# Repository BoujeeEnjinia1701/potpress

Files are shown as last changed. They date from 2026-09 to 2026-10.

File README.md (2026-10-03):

# PotPress

     

**Area:** Water Security · **TRL:** 3 of 9 (proof of concept on paper) · **Value-engineering target:** $1,060 USD · **Difficulty:** 3 of 5

Hydraulic press with printable mold geometry for silver-treated ceramic pot filters, plus a QC flow-rate test jig.

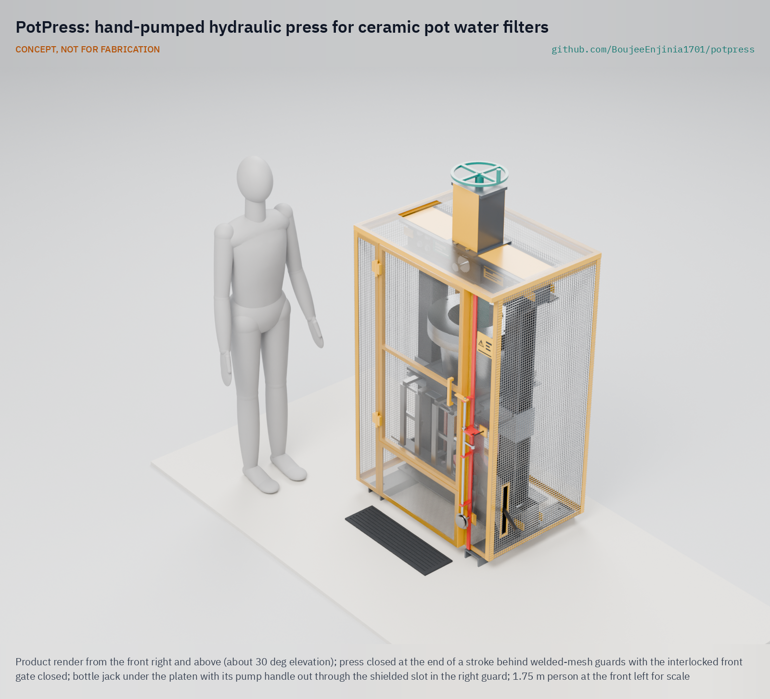
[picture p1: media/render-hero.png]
PotPress: hand-pumped hydraulic press for ceramic pot water filters, product render


[Exploded render](media/render-exploded.png) · [Gate open render](media/render-gate-open.png) · [Lineup render](media/render-lineup.png) · [Interactive 3D model](media/viewer.html) · [Concept blueprint (PDF)](media/concept-blueprint.pdf) · [General arrangement PPR-DWG-001 (PDF)](cad/drawings/PPR-DWG-001.pdf) · [Sizing note PPR-CAL-001](docs/04-calcs/01-sizing.md) · [Prototype build plan](docs/05-build-plan.md) · [Review note](docs/REVIEW.md)

## Concept rationale

The ceramic pot filter already works; what holds small factories back is the press that forms it. A hydraulic press built from standard steel channel, a car-shop bottle jack and molds cast by any aluminum foundry from 3D-printed patterns can be made and repaired in the regions where the filters are needed, instead of imported at several thousand dollars. Every dimension of the pot, the molds, the patterns and the flow gauge comes from one parametric file, so a factory that changes its filter size regenerates all of them together rather than redrawing by hand.

Keeping the design open matters because filter quality depends on details (an even wall, a consistent flow test) that each workshop now solves alone. An open, garage-buildable press lets factories, NGOs and university labs share improvements, compare results on the same geometry and build a second press when the first wears out.

## Burning platform

About 2.1 billion people still lacked safely managed drinking water in 2024, and 106 million drank untreated surface water ([WHO and UNICEF JMP, 2025](https://www.who.int/news/item/26-08-2025-1-in-4-people-globally-still-lack-access-to-safe-drinking-water---who--unicef)). WHO estimates that microbiologically contaminated drinking water causes about 505,000 diarrheal deaths each year, and that at least 1.7 billion people used a drinking water source contaminated with feces in 2022 ([WHO fact sheet, Drinking-water](https://www.who.int/news-room/fact-sheets/detail/drinking-water)).

Locally made ceramic pot filters are an established household option: filters based on the Potters for Peace technology are now made at over 50 independent factories in over 30 countries ([Potters for Peace](https://www.pottersforpeace.org/ceramic-water-filter-project)). Yet a filter press with its aluminum molds cost $3,000 to $3,500 to acquire, and a locally built Nigerian press still cost about $1,000 ([Erhuanga et al., IntechOpen, 2020](https://www.intechopen.com/chapters/71402)). The press is the gate on how many factories can start.

## Where it could be used

### By industry

| Industry | Use |
| --- | --- |
| Household water treatment enterprises | Form filters with an even wall at a small factory and check every one on the QC rack |
| Pottery and ceramics cooperatives | Add filter production to an existing kiln and clay supply with a press they can build and repair |
| Humanitarian and disaster response | Set up filter production near displaced or flood-hit communities without importing a press |
| Public health programs | Supply consistent filters to household water programs and record QC results the same way at every site |
| University and research labs | Study mix, pressing and firing variables on a repeatable press and shared geometry |
| Local fabrication shops and foundries | Build frames and cast molds from open drawings as a local service |

### By country or region

| Country or region | Why it matters there |
| --- | --- |
| Nicaragua | After Hurricane Mitch in October 1998, Potters for Peace set up its first filter production workshop here and distributed over 5,000 filters within six months ([Potters for Peace](https://www.pottersforpeace.org/ceramic-water-filter-project); [University of Pittsburgh](https://www.engineering.pitt.edu/subsites/projects/ceramic-filter/history/)) |
| Guatemala | The filter was designed here in 1981 by Dr. Fernando Mazariegos at the Central American Industrial Research Institute (ICAITI) ([Potters for Peace](https://www.pottersforpeace.org/ceramic-water-filter-project)) |
| Cambodia | One of the countries where Potters for Peace has trained filter producers ([Potters for Peace](https://www.pottersforpeace.org/ceramic-water-filter-project)); a shared press design would let new workshops match established ones |
| Nigeria | A locally built press cost about $1,000 against $3,000 to $3,500 for an imported press and molds, and the team struggled to find a lathe large enough to finish the molds ([Erhuanga et al., IntechOpen, 2020](https://www.intechopen.com/chapters/71402)) |
| United States | The University of Pittsburgh runs research and service-learning projects on filter manufacturing variables, such as sawdust particle size and firing rate, and gives technical support to NGOs that make filters ([University of Pittsburgh](https://www.engineering.pitt.edu/subsites/projects/ceramic-filter/research--activities/)); an open press gives such labs a common reference |

## What sparked the idea

The starting point was the Potters for Peace filter workshop in Nicaragua. Ron Rivera coordinated the organization's work there from 1989, and after Hurricane Mitch tore through Central America in October 1998, Potters for Peace became much more involved in the low-cost filter and set up its first filter production workshop, which distributed over 5,000 filters within six months ([University of Pittsburgh](https://www.engineering.pitt.edu/subsites/projects/ceramic-filter/history/); [Potters for Peace](https://www.pottersforpeace.org/ceramic-water-filter-project)). Its filters are formed with a hand-operated hydraulic truck jack and a two-piece aluminum mold, and filters based on that technology package are now made at over 50 independent factories in over 30 countries ([Potters for Peace](https://www.pottersforpeace.org/ceramic-water-filter-project)). PotPress takes that jack-and-mold principle and asks what it would look like as an openly maintained, parametric design, so that the next workshop can build its press and molds from shared files rather than from a one-off drawing.

## Problem

Ceramic pot filters work well, but local producers have no low-cost way to form them consistently. Imported presses cost about $3,000 to $3,500, locally built ones are one-off designs, and filter quality depends on an even wall and a consistent flow-rate check. Design with, not for: requirements must come from co-design sessions and trials with a working filter factory through a local partner.

## Concept

A 20 t bottle jack on the base lifts a guided platen carrying a cast aluminum female mold against a fixed male mold, forming one filter (280 mm inner rim, 9.9 L working volume) per stroke. The male mold is held by one 60 mm load pin in the top crossbeam for pressing and raised by a hand crank for loading, and the female mold slides out on a carriage for demolding. One parametric filter geometry drives the molds, their 3D-printed casting patterns and a printed T-gauge for the four-station, one-hour flow-rate test rack. TRL 3 calculations: a cycle of about 5.2 min and about 69 pots per 6 h, a frame that stays below yield at 1.5 times the jack rating, 0.66 mm of deflection between the molds at the 10 t working force, every part under 40 kg with the upright joints bolted, and, with the fixed mesh guards and interlocked front gate decided by Amish on 2026-09-26, $1,051 in parts against the $1,060 budget, which Amish raised from $990 on 2026-09-27 to cover the guards. Making the design constructable on 2026-09-30, and adding the fixed shield behind the pump slot on 2026-10-02, raised the parts to about $1,149, and the four guard fixes Amish decided on 2026-10-03 (finer 6.35 mm mesh on the front, gate and roof, small-hole plates at the interlock openings, cover plates on the top beam, covers on the crank bracket) to about $1,169. Value-engineering target: USD 1,060. Estimated cost of the constructable design: USD 1,169 (USD 109 over the target). With those fixes the ISO 13857 desk check of the guard openings, rerun from the model on 2026-10-03, finds every opening meets the standard on paper; nothing above hand pressure is allowed until a competent person signs the check.

Full design precis: [docs/02-concept.md](docs/02-concept.md)

## Key components

- Steel channel frame in welded subassemblies: two UPN 160 beams and back-to-back UPN 100 uprights, bolted at the upright joints with 4 x M16 10.9 each, with spacer tubes and shims
- 20 t bottle jack, guided moving platen and return springs
- Cast aluminum shell molds (female 36.5 kg on its steel base plate, male 23 kg), cast from 3D-printed flat-back patterns and located by two dowels
- Mold carriage on slide rails with a hinged front extension that folds down, and male mold slide with hand crank, one load pin and a pin-presence interlock
- Four-station (2 x 2) QC flow-test rack with printed T-gauges and collection buckets

The working bill of materials is in [bom/bom.csv](bom/bom.csv).

## Building the prototype

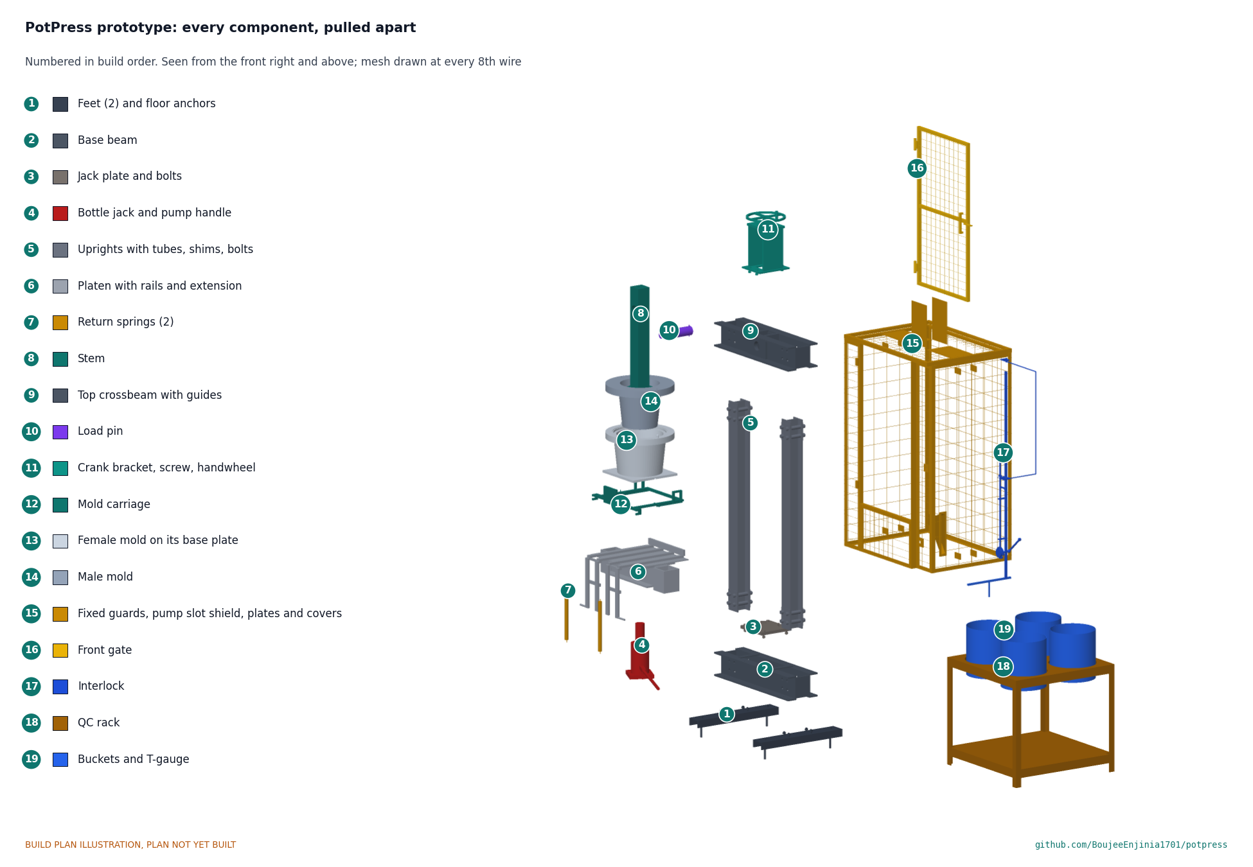
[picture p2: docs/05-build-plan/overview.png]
Every component of the PotPress prototype, pulled apart and numbered in build order


The [prototype build plan](docs/05-build-plan.md) (PPR-BLD-001, plan, not yet built) shows how to make each component and fit it to the next, in 14 making sketches, 11 joint close-ups and 18 assembly steps drawn from the model. The frame, platen, carriage and guards are sawn, drilled and stick welded from steel channel, plate and galvanized mesh; the two molds are sand cast by a local foundry from 3D-printed flat-back patterns and lead-free scrap, then lapped and hand finished, with no lathe needed. Writing the plan made the design constructable: seventeen changes, such as an open-topped male mold, dowel location for the molds, M16 joint bolts with spacer tubes and a floating lead screw nut, are recorded in [PPR-DDR-004](docs/decisions/0004-design-for-construction.md). The parts now cost about $1,169, $109 over the $1,060 value-engineering target, a hypothetical control target; the design decisions register lists the savings worth trying.

## Safety

> **Safety:** Hydraulic presses store significant energy. Guard pinch points, press only with the gate closed and the load pin fully home (the interlock enforces this), and never exceed the jack rating. Molds are heavy; clay dust contains silica; silver compounds are corrosive. Passing the flow test does not prove a filter removes pathogens. See the safety section of the [design precis](docs/02-concept.md).

## Repository layout

| Folder | Contents |
| --- | --- |
| `docs/` | Problem, concept, requirements, calculations and design decisions |
| `cad/src/` | build123d Python source, the source of truth for all geometry |
| `cad/step/`, `cad/stl/` | Exported models for FreeCAD, other CAD tools and printing |
| `cad/drawings/` | 2D sketches and dimensioned drawings |
| `bom/` | Bill of materials |
| `electronics/` | KiCad schematics and PCB layouts |
| `firmware/` | Microcontroller code |
| `media/` | Renders, perspectives and photos |
| `build-log/` | Dated prototyping notes |

## Documentation

Controlled documents follow the portfolio [documentation standard](.kit/STANDARDS.md). Each carries a document ID (PPR-PRC-001 for the precis), a version and a revision history. Branded PDFs are built with `python .kit/render.py` and attached to GitHub Releases when a document is tagged, for example `PPR-PRC-001/v1.0`.

## Credits

Designed by Amish Chadha. See [CONTRIBUTORS.md](CONTRIBUTORS.md) for roles. To cite this design, use [CITATION.cff](CITATION.cff) (GitHub shows it as "Cite this repository").

AI assistance (Claude) was used to accelerate concept renders, prototype documentation and first-pass sizing calculations. Design direction and all decisions are Amish Chadha's, recorded in this repository's decision records (`docs/decisions/`).

## Licenses

- **Hardware** (CAD, drawings, BOM, electronics): [CERN-OHL-S v2](LICENSE)
- **Software** (firmware, scripts, notebooks): [MIT](LICENSE-SOFTWARE)

A project of the [Design Molecule](https://designmolecule.com) lab.

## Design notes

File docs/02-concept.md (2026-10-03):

---
doc_id: PPR-PRC-001
title: PotPress design precis
project: PotPress
doc_type: Design precis
version: "0.11"
status: Draft
date: '2026-10-03'
author: Amish Chadha
license: CERN-OHL-S-2.0
revisions:
- version: "0.1"
  date: '2026-09-24'
  author: Amish Chadha
  change: Initial scaffold
- version: "0.2"
  date: '2026-09-25'
  author: Amish Chadha
  change: Populate to TRL 2 (architecture, first-order numbers, material flow, safety, media)
- version: "0.3"
  date: '2026-09-25'
  author: Amish Chadha
  change: TRL 3 update; design choices decided by Amish (PPR-DDR-001); numbers corrected to PPR-CAL-001 (shell molds, 2 x UPN 160 base, one 60 mm pin, 2 x 2 QC rack, cost)
- version: "0.4"
  date: '2026-09-25'
  author: Amish Chadha
  change: Recommendations accepted by Amish (DDR-002); bolted upright joints, hinged rail extension, pin-presence interlock, lead-free scrap, budget $930; numbers from PPR-CAL-001 v0.2
- version: "0.5"
  date: '2026-09-26'
  author: Amish Chadha
  change: Budget top-up approved by Amish; budget $990, R10 met on paper
- version: "0.6"
  date: '2026-09-26'
  author: Amish Chadha
  change: Guarded version (decided by Amish 2026-09-26)
- version: "0.7"
  date: '2026-09-27'
  author: Amish Chadha
  change: Cost overrun decided by Amish on 2026-09-27; budget $1,060, R10 met on paper
- version: "0.8"
  date: '2026-10-01'
  author: Amish Chadha
  change: Budget treated as a value-engineering target
- version: "0.9"
  date: '2026-10-02'
  author: Amish Chadha
  change: 'Decisions of 2026-10-02 carried in: ISO 13857 desk check now as a hold point, pump slot inner shield, handle operating space, working force found in trials from about 2 t, demolding confirmed with potters'
- version: "0.10"
  date: '2026-10-02'
  author: Amish Chadha
  change: 'Approved follow-ups carried out: pump slot shield designed; ISO 13857 desk check done (PPR-CAL-001 v0.9) with its findings; cost $1,149'
- version: "0.11"
  date: '2026-10-03'
  author: Amish Chadha
  change: 'Four guard fixes decided by Amish (2026-10-03): 6.35 mm mesh on the front and roof, small-hole plates, top beam cover plates, crank bracket covers; desk check rerun, every opening meets on paper; R9 met on paper; cost $1,169'
---

# PotPress design precis

PotPress is a hand-pumped hydraulic press that forms one ceramic pot filter per stroke between a cast aluminum female mold and male mold, plus a four-station rack for the standard one-hour flow-rate test. A 20 t bottle jack on the base lifts a guided platen carrying the female mold against a fixed male mold, whose stem is held by one load pin in the top crossbeam for pressing and raised by a hand crank for loading. One parametric filter geometry drives the molds, the 3D-printed casting patterns and the printed flow gauge. The TRL 3 calculations (PPR-CAL-001) give a cycle of about 5.2 min and about 69 pots per 6 h, a strong frame at 1.5 times the jack rating, every part under 40 kg with the frame bolted at the upright joints, and, in the guarded version, a parts cost of $1,051 against the $1,060 value-engineering target (the target stood at $990 before the guards were added, PPR-DDR-003). The press works inside fixed welded-mesh guards with a hinged front gate that is interlocked with the jack release, as decided by Amish on 2026-09-26 (PPR-DDR-003). The other design choices below were decided by Amish on 2026-09-25 (PPR-DDR-001 and PPR-DDR-002).

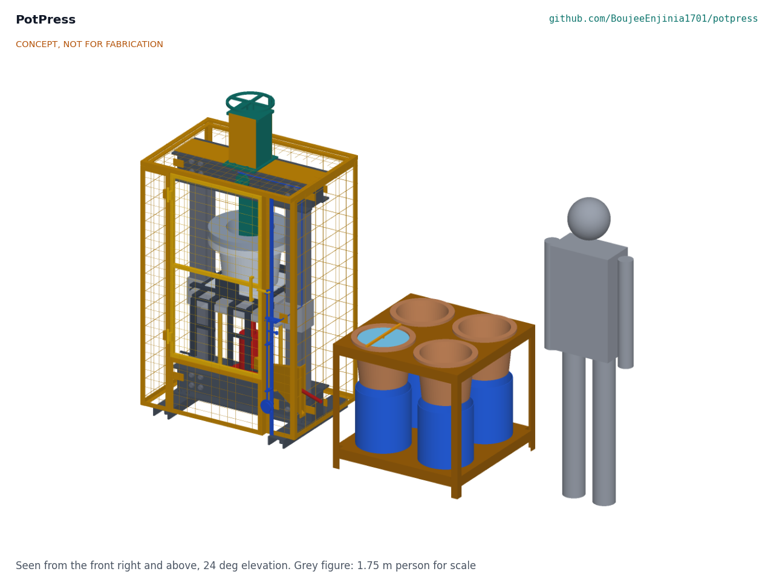
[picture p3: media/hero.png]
Hero render


*Figure 1. PotPress with the 2 x 2 QC flow-test rack and a 1.75 m person for scale. The press is shown closed at the end of a pressing stroke, inside its mesh guards with the front gate closed; the mesh is drawn at every eighth wire.*

## How it works

1. **Load.** With the platen down and the jack release open, the female mold rim is at about 921 mm. The operator opens the front gate, swings the hinged rail extension up onto its stop lugs, slides the carriage out 430 mm on the rails, lays a polyethylene release liner in the female mold, places a weighed charge of about 7.5 kg of clay, burnout and water mix, and slides the carriage back to its end stop.
2. **Lower the male mold.** A handwheel on top of the frame turns a self-locking Tr24 x 5 lead screw that runs the male mold stem down 200 mm (40 turns) through the top crossbeam until the pin bores line up. The operator inserts the 60 mm load pin through the beam and stem. From then on the pin, not the screw, carries the press force.
3. **Press.** The operator closes the front gate, which lets the guard-locking interlock free the jack release T-handle; closing the release locks the gate shut. The operator then pumps the jack through the slot in the right side guard, about 70 strokes. The platen, guided by sleeves on both uprights, lifts the female mold about 110 mm and squeezes the charge into the gap between the molds. The male flange centers in a tapered lip on the female mold and lands on a stop face, so the 15 mm wall and rim are set by the molds, not by how hard the operator pumps. Excess mix squeezes into a flash groove at the rim for trimming.
4. **Open and demold.** The operator opens the jack release with the T-handle outside the guard; the platen's weight and two springs return it, and only then does the interlock let the gate open. The operator pulls the pin and cranks the male mold up, leaving its tip 70 mm above the female rim. The carriage slides out toward the operator and tilts on its pivots so the pot, still in its liner, turns out onto a drying board. Between loads the rail extension folds down, so the press stands 840 x 655 mm.
5. **Dry, fire, treat.** Drying, firing and silver treatment follow the factory's existing practice and are outside PotPress.
6. **Test.** Fired pots are soaked, hung by their rims in the QC rack over collection buckets, filled to 10 mm below the rim and read after one hour with the printed T-gauge. The reading is corrected to 25 °C with the water temperature.

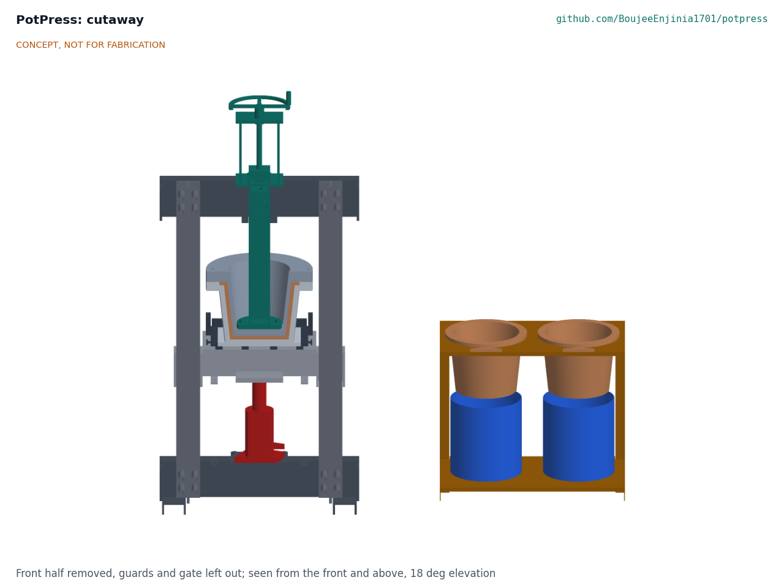
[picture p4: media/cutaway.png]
Cutaway


*Figure 2. Cutaway through the closed press and the QC rack, showing the pressed pot between the molds, the shell molds and the load path.*

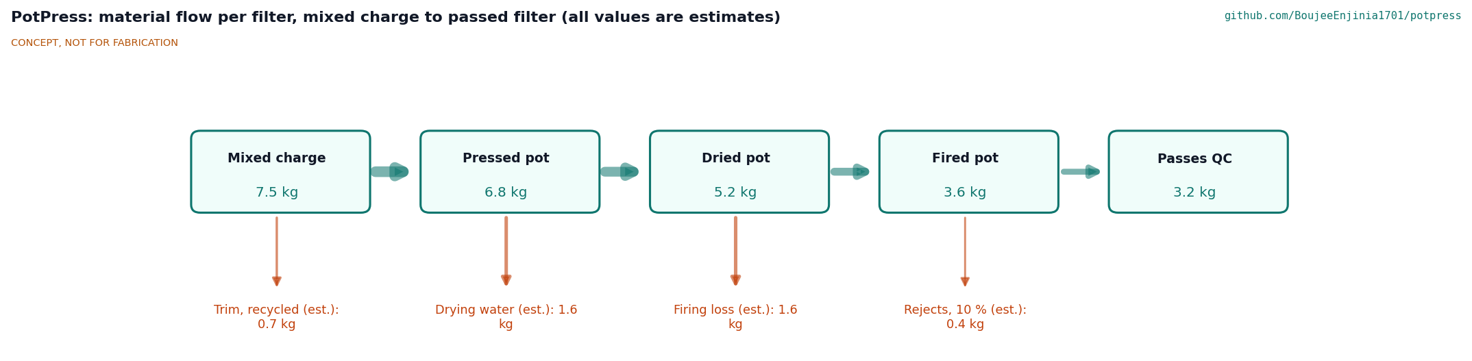
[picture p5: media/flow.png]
Material flow


*Figure 3. Material flow for one filter, from mixed charge to a filter that passes QC, in kg. All values are estimates from PPR-CAL-001.*

## Main components

Numbers match the exploded view (Figure 4), `bom/bom.csv` and the general arrangement drawing PPR-DWG-001.

*Table 1. Main components.*

| # | Component | Choice | Notes |
| --- | --- | --- | --- |
| 1 | Base beam and feet | Two UPN 160 channels 840 mm with a 100 mm gap, 20 mm jack plate, two UPN 100 feet bolted on | Same section as the top beam; the TRL 2 single UPN 100 would reach about 1,071 MPa |
| 2 | Uprights | Two UPN 100 channels back to back each side, about 1.40 m, sandwiched in the beam gaps at 600 mm centers and bolted to both beams with 4 x M20 8.8 per joint | 54 MPa in tension, bolts 75 MPa in double shear at 294 kN; 29.4 kg per pair |
| 3 | Top crossbeam | Two UPN 160 channels, 12 mm web doublers and a 62 mm pin bore at the center, UHMW-PE stem guides | 190 MPa at 294 kN |
| 4 | 20 t bottle jack | Standard jack, 150 mm stroke, about 60 mm ram | Uses 110 mm of stroke |
| 5 | Moving platen | Two UPN 140 channels, 6 mm deck, jack pad, 150 mm guide sleeves on the uprights | 38.9 kg, the heaviest part as fabricated |
| 6 | Return springs | Two tension springs | Gravity returns the platen; the springs keep it seated |
| 7 | Rails, hinged extension and carriage | Four flat-bar rails at 60 and 170 mm each side, fixed to 320 mm in front of the axis, with a 330 mm extension on barrel hinges and stop lugs that folds down; carriage frame with handle and tilt pivots | Moves the female mold out of the pinch zone; 43 N·m on the hinge with the carriage out |
| 8 | Female mold | Cast aluminum shell, 20 mm behind the cavity, 30 mm solid base, 410 mm flange with a locating lip, rim counterbore and flash groove; 24.3 kg | A solid block would weigh about 57 kg |
| 9 | Male mold | Cast aluminum hollow plug, 15 mm shell and 30 mm tip, 390 mm rim-forming flange; 17.9 kg | A solid plug would weigh about 41 kg |
| 10 | Male mold slide | SHS 90 x 8 stem with a pin block, one 60 mm 42CrMo4 load pin, crank bracket, Tr24 x 5 lead screw and 260 mm handwheel | The screw only lifts; the pin carries the load |
| 11 | Pressed filter pot | The product, shown for context | Not costed |
| 12 | QC flow-test rack | 2 x 2 stations, 780 x 780 x 550 mm, steel angle and plywood | Within R11's 0.8 x 0.8 m |
| 13 | Printed T-gauge | PETG dipstick; 1.0 L is 16.7 mm on the scale | Scale generated from the geometry |
| 14 | Collection buckets | 20 L food-grade HDPE | |
| 16 | Fixed mesh guards, pump slot shield and guard fixes | Welded mesh on 25 x 25 x 3 angle frames: 12.7 x 12.7 x 1.6 mm (about 11 mm clear) on both sides and the back; 6.35 x 6.35 x 0.9 mm (about 5.5 mm clear) on two front strips, a lower front panel and a roof around the top beam; standoffs to the beams; a framed 30 x 272 mm pump handle slot in the right side with a fixed inner shield behind it, a tunnel of 2 mm sheet round the handle's path to the jack body; small-hole plates at the release shaft and pin cable; 3 mm cover plates on the top beam; 2 mm covers on the crank bracket | Mesh planes 940 x 675 mm; about 4.3 m² of mesh, 1.1 m² of it 6.35 mm; shield 2.8 kg; plates and covers 4.4 kg |
| 20 | Front gate | 532 x 1,063 mm, 20 x 20 x 2 tube frame with 6.35 mm mesh (2026-10-03), two lift-off hinges on the left front post, pull handle and striker tongue; opens outward to the left | Clears the carriage, molds and rail extension (540 mm opening) |
| 21 | Gate interlock and release extension | Mechanical guard-locking bolt on the right front post, link rod and lock bar to a blocking cam on the jack release extension; T-handle outside the lower front panel; the pin-presence plunger acts on the same lock bar | No electrics |

Casting patterns, release liners, fasteners and consumables, and the QC timer and thermometer are BOM items 15 and 17 to 19 and are not modeled. The guards are modeled with their mesh drawn at every eighth wire (101.6 mm) so the views stay readable; the appearance model draws every wire.

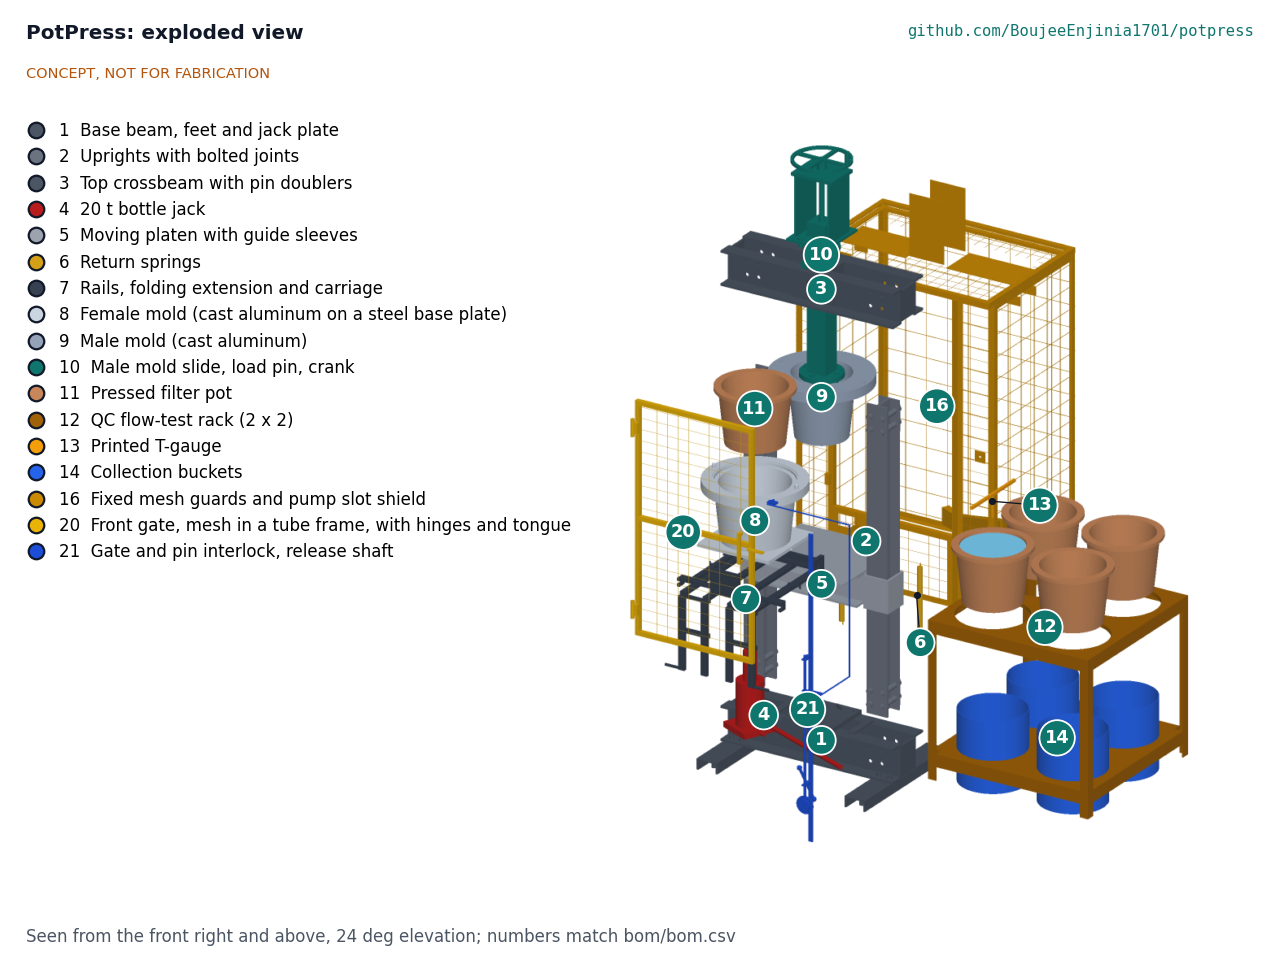
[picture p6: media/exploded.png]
Exploded view


*Figure 4. Exploded view with numbered callouts matching the BOM.*

## Key numbers

All values are estimates from PPR-CAL-001, which lists its assumptions and the results against every requirement.

*Table 2. Key numbers at TRL 3.*

| Quantity | Value | Basis |
| --- | --- | --- |
| Filter volume | 12.30 L to the brim; 9.91 L working | Inner rim 280 mm, floor 230 mm, depth 240 mm |
| Pot masses | Charge 7.47 kg; pressed 6.79 kg; fired 3.61 kg | RDI-C recipe, 1.64 kg/L pressed |
| Mean pressure | 0.52 to 1.05 MPa at 5 to 10 t; 2.10 MPa at 20 t | 0.0935 m² projected |
| Frame at 294 kN | Beams 190 MPa, uprights 54 MPa, pin 258 MPa (yield 650), joint bolts 75 MPa | S275; 42CrMo4 pin; M20 8.8 bolts |
| Deflection between molds | 0.61 mm at 10 t; 1.84 mm at 294 kN | R3 (1 mm at 10 t) met on paper |
| Travel | 110 mm pressing of 150 mm stroke; 310 mm opening against 270 mm needed | R5 met |
| Cycle | 5.2 min; 69 pots per 6 h | R4 met |
| Wall evenness | ±1.40 mm as cast; ±0.43 mm finished to templates | R2 at risk |
| Flow gauge | 0.1 L is 1.69 mm; 2.3 % per °C near 25 °C | R6 met |
| Size and mass | Press 840 x 655 x 1,806 mm unguarded; 940 x 700 mm guarded, with the rail extension folded; 298 kg plus 7 kg of joint bolts and about 45 kg of guards (estimate); heaviest part 38.9 kg; rack 780 x 780 mm | R8 met on paper; R11 met on paper at the 0.7 m limit |
| Guarding | Mesh 12.7 mm pitch at the sides and back, 100 to 110 mm from moving parts; 6.35 mm pitch on the front, gate and roof, 39 to 77 mm from moving parts; pump slot enclosed by a fixed inner shield; interlock openings closed to 4 and 2 mm gaps; top beam and crank bracket covered | ISO 13857 desk check rerun from the model on 2026-10-03 with the four guard fixes decided by Amish (PPR-CAL-001, section 15): all 23 openings meet on paper; not yet signed; R9 met on paper |
| Cost | Press $1,086, QC rack $83, total $1,169 (constructable design with the pump slot shield and the guard fixes) | Value-engineering target: USD 1,060. Estimated cost of the constructable design: USD 1,169 (USD 109 over the target) |

The working force is still an assumption. Henry, Maley and Mehta (2013) formed round-bottom filters with a 2 t car jack ([IJSLE 8 (1)](https://ojs.library.queensu.ca/index.php/ijsle/article/view/4532)), which suggests the real force may be well below 5 to 10 t; the frame is sized for the full 20 t jack either way. Decided by Amish on 2026-10-02: every structural check stays at the full 20 t jack, and the working force is a process setting found in pressing trials with a partner factory, starting near 2 t and stepping up.

## Key design choices

These were decided by Amish on 2026-09-25: go with recommendation (PPR-DDR-001 items 1 to 8 and 10 to 15; PPR-DDR-002), except the guarded version, decided by Amish on 2026-09-26 (PPR-DDR-003).

- **Jack below, pushing the female mold up.** A bottle jack must stand upright, so it sits on the base and lifts the platen, and the male mold hangs from the top beam.
- **Male mold lift by hand crank with one load pin and an interlock.** A standard jack gives only 150 mm of stroke, so the crank provides the other 200 mm of opening. The TRL 2 pair of 30 mm pins fails in bending by calculation; one 60 mm alloy-steel pin carries the force, and a mechanical pin-presence interlock stops the jack release valve closing unless the pin is fully home.
- **Molds cast in aluminum from printed patterns, from lead-free scrap.** Cast as shells to keep them under 25 kg, with the cavity finished by hand to printed templates. Scrap must be lead-free (for example cast wheels or pistons; no free-machining bar). The fiber-reinforced concrete backed variant stays documented as a low-cost alternative; building it is TRL 4 work and on hold.
- **Welded subassemblies, bolted at the upright joints.** The base beam, top beam, uprights and platen are welded separately and joined with 4 x M20 8.8 bolts at each of the four upright joints, so no part exceeds 40 kg. Fully welded, the frame would be one 147 kg piece.
- **Molds close on a metal stop.** The male flange lands on the female stop face, so frame stretch does not set the wall; R3 judges deflection at the 10 t working force.
- **Demold by sliding out and tilting the carriage,** on a rail extension that folds down between loads.
- **Manual QC rack with printed T-gauge.** The rack is 2 x 2 stations in 0.8 x 0.8 m; a load-cell logger stays a later option.
- **Default acceptance band 1.0 to 2.5 L/h in the first hour, corrected to 25 °C.** Each factory may set its own band.
- **Value-engineering target $1,060.** This is a hypothetical control target, not a limit. The priced BOM was $984 after the bolted joints and rail hinges, against a $990 target. The guarded version adds $67 and brings the BOM to $1,051, $61 over that earlier target; the target was set at $1,060 on 2026-09-27, since guarding is a safety requirement (PPR-DDR-003). The estimate was then within the target, $9 (0.8 %) under; the constructable design (PPR-DDR-004) and the pump slot shield (2026-10-02) bring it to $1,149, and the four guard fixes Amish decided on 2026-10-03, accepting their cost, to $1,169, $109 over the target.
- **Guarded version (decided by Amish, 2026-09-26; PPR-DDR-003).** Fixed welded-mesh guards on the sides, back and roof, and a hinged front gate with a mechanical guard-locking interlock on the jack release. A hand pump has no power to switch off, so the interlock acts on the one thing that lets the jack build pressure: the release valve. With the gate open the release cannot be closed, so pumping moves nothing; with the release closed the gate cannot be opened. This was chosen over two-hand control, which does not suit a one-handed pump lever, and over hold-to-run alone, which a hand pump already is but which leaves the other hand free to reach the molds.

## Safety

> **Safety:** PotPress is a 20 t hydraulic press with heavy moving parts, and the workshop around it handles silica-bearing clay dust and silver compounds. Treat each of these as a hazard at every stage.

- **Crushing and pinch points.** The gap between the molds, the platen and the uprights, and the carriage rails can crush fingers and hands. The guarded version (PPR-DDR-003) encloses them: fixed welded-mesh guards on the sides, back and roof, fixed front strips and a lower front panel, and a hinged front gate. The gate's guard-locking interlock holds the jack release open unless the gate is shut, and holds the gate shut while the release is closed. The pump handle works through a framed slot in the right side guard, well below the platen, with a fixed steel tunnel behind the slot so that only the handle can be reached through it, and the release T-handle sits outside the lower front panel. The carriage has an end stop so it cannot be pushed past the male mold. Keep fingers clear of the rail extension hinges when folding it, and deploy it only onto its stop lugs; the extension cannot be deployed with the gate shut.
- **Guard openings (ISO 13857 desk check, 2026-10-02, rerun 2026-10-03).** Decided by Amish on 2026-10-02: the check is done now as a desk check from the tables and the model's distances, signed by a competent person, and is a hold point before any force above hand pressure. The first run found the 12.7 mm mesh on the front and roof too coarse for its 39 to 77 mm distance from moving parts, the release shaft and pin cable openings too large, and the top beam and crank bracket open from above. Amish decided on 2026-10-03: "PotPress - move forward with the four guard fixes. I accept the cost." The front strips, lower front panel, front gate and roof now carry 6.35 mm (1/4 in) mesh with 0.9 mm wire, about 5.5 mm clear, which Table 4 allows 5 mm from a moving part; plates close the two interlock openings to a 4 mm gap round the release shaft and 2 mm round the pin cable; 3 mm plates cover the top beam from the crank bracket to the beam ends, including the open tops of the upright channels; 2 mm sheet closes the front and back of the crank bracket. The sides and back keep the 12.7 mm mesh, 100 to 110 mm from moving parts, and the 30 x 272 mm pump slot stays enclosed by its fixed inner shield. The rerun check finds every one of the 23 openings meets on paper (PPR-CAL-001, section 15). The check is not yet signed; nothing above hand pressure until it is. The 158 mm the pump handle stands outside the guard while in use is operating space, marked on the floor layout. Never remove a guard or defeat the interlock, and inspect both before each shift.
- **Load pin and stored energy.** One 60 mm pin carries the whole press force. Never press unless the pin is fully home through both beam webs and the stem; the guard includes a pin-presence interlock that stops the jack release closing until the pin is home. Check the bolted upright joints for tightness before each shift. Never exceed the jack rating, never add a cheater bar to the pump handle, and never adjust the jack's relief valve. Release pressure fully before opening the gate or pulling the pin.
- **Falling and tipping.** The molds weigh about 24 and 18 kg and the press about 305 kg with its bolts, with its center of mass about 0.8 m up. A push of about 750 N at 1 m tips it forward, so anchor the base to the floor, lift molds with two people and wear safety boots. The lead screw is self-locking, so the male mold holds its height if the handwheel is released; still keep hands out from under it.
- **Silica dust.** Dry clay and rice husk ash contain crystalline silica, which causes silicosis. Keep mixing and trimming wet, sweep damp, and wear a fitted P2 or N95 respirator for dry work.
- **Molten aluminum and alloy.** Casting is done by a foundry, not at the press. Scrap containing lead (free-machining alloys) must not be used for mold faces that touch a drinking-water product.
- **Silver compounds.** Silver nitrate is corrosive to skin and eyes and toxic to aquatic life; handle colloidal silver with gloves and eye protection and never pour it into waterways. Silver treatment is outside PotPress but happens in the same workshop.
- **Heat.** Kilns reach about 900 °C. Kilns are outside PotPress but share the site.
- **Water safety claims.** PotPress makes consistent pots; it does not certify them. A filter that passes the flow test is not proven to remove pathogens. Factories must verify bacteria removal by laboratory testing and follow the CMWG recommendations.

## Open questions

- What pressing force gives a well-consolidated wall with a typical mix? Found in pressing trials with a partner factory, starting near 2 t and stepping up (decided, 2026-10-02).
- Can hand finishing to printed templates reach ±0.3 mm on a 400 mm casting (R2, R7)?
- Handwheel height of about 1.8 m: a side crank through a bevel gear would be easier to reach.
- Confirm the demolding method with the potters at the first partner factory; the tipping pins stay for the prototype, and if the potters object the pot is lifted out in its liner (decided, 2026-10-02). Check whether a liner leaves marks that affect flow.
- Choose the first partner factory or organization (left open under the portfolio rule).

Concept media: [blueprint sheet](../media/concept-blueprint.pdf), [interactive 3D model](../media/viewer.html). General arrangement: [PPR-DWG-001](../cad/drawings/PPR-DWG-001.pdf).

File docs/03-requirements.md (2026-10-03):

---
doc_id: PPR-REQ-001
title: PotPress requirements
project: PotPress
doc_type: Requirements
version: "0.12"
status: Draft
date: '2026-10-03'
author: Amish Chadha
license: CERN-OHL-S-2.0
revisions:
- version: "0.1"
  date: '2026-09-24'
  author: Amish Chadha
  change: Initial scaffold
- version: "0.2"
  date: '2026-09-25'
  author: Amish Chadha
  change: First measurable requirements for TRL 2, with concept status
- version: "0.3"
  date: '2026-09-25'
  author: Amish Chadha
  change: Apply Amish's 2026-09-25 decisions (PPR-DDR-001); R10 target $720, R6 band decided; status from PPR-CAL-001; proposed changes to R3 and R11
- version: "0.4"
  date: '2026-09-25'
  author: Amish Chadha
  change: Recommendations accepted by Amish (DDR-002); R3 at 10 t with a metal stop, R9 pin interlock, R10 $930, R11 rack 0.8 x 0.8 m and folded rails, R12 lead-free scrap; status from PPR-CAL-001 v0.2
- version: "0.5"
  date: '2026-09-26'
  author: Amish Chadha
  change: Budget top-up approved by Amish; R10 target $990, status met on paper
- version: "0.6"
  date: '2026-09-26'
  author: Amish Chadha
  change: Guarded version (decided by Amish 2026-09-26)
- version: "0.7"
  date: '2026-09-27'
  author: Amish Chadha
  change: Cost overrun decided by Amish on 2026-09-27; R10 target $1,060, status met on paper
- version: "0.8"
  date: '2026-09-30'
  author: Amish Chadha
  change: Status from PPR-CAL-001 v0.6 after the design for construction (PPR-DDR-004); R10 not met on paper; no requirement text changed
- version: "0.9"
  date: '2026-10-01'
  author: Amish Chadha
  change: Budget treated as a value-engineering target; R10 reported against the target
- version: "0.10"
  date: '2026-10-02'
  author: Amish Chadha
  change: 'Decisions of 2026-10-02: R9 at risk until the pump slot shield is designed and the ISO 13857 desk check is signed; R9 verification and the force assumption restated'
- version: "0.11"
  date: '2026-10-02'
  author: Amish Chadha
  change: 'Approved follow-ups carried out: pump slot shield designed and modelled; ISO 13857 desk check done from the model (PPR-CAL-001 v0.9), R9 at risk to not met on paper until the guard changes it found are made and the check is signed; R10 $1,149, $89 over the target'
- version: "0.12"
  date: '2026-10-03'
  author: Amish Chadha
  change: 'Four guard fixes decided by Amish (2026-10-03) modelled; desk check rerun (PPR-CAL-001 v0.10), all 23 openings meet on paper; R9 not met to met on paper (check not yet signed); R10 $1,169, $109 over the target'
---

# PotPress requirements

These requirements were checked by calculation at TRL 3 (PPR-CAL-001 v0.10). They are not yet validated with a filter factory and will be revised after co-design sessions (see PPR-PRB-001). With the design made constructable (PPR-DDR-004, 2026-09-30), one is over the value-engineering target (R10, the parts cost of $1,169 against the $1,060 target, $109 over), two are at risk (R2 and R7) and nine are met on paper, R9 among them since the four guard fixes Amish decided on 2026-10-03 close every opening the ISO 13857 desk check found short (the check is not yet signed by a competent person); see Table 2. Amish's decisions of 2026-09-25 are recorded in PPR-DDR-001 and PPR-DDR-002: the R6 default band, R3 judged at the 10 t working force, the R10 target of $930 (topped up to $990 by Amish on 2026-09-26 and raised to $1,060 by Amish on 2026-09-27, PPR-DDR-003), the R11 rack area of 0.8 x 0.8 m, the pin-presence interlock in R9 and lead-free scrap in R12. The guarded version and the guarding detail in R9 were decided by Amish on 2026-09-26 (PPR-DDR-003).

The **reference filter** used throughout is the common flowerpot form: inner rim diameter 280 mm, inner depth 240 mm, wall 15 mm, flat rim about 345 mm across, about 12 L to the brim and about 10 L working volume (dimensions are estimates based on the 280 by 250 mm form reported by [Potters for Peace](https://www.pottersforpeace.org/ceramic-water-filter-project)).

*Table 1. Requirements.*

| ID | Requirement | Target | Verification (TRL 3 or later) |
| --- | --- | --- | --- |
| R1 | Form the reference filter | Inner rim 280 mm, inner depth 240 mm, wall 15 mm, flat rim; geometry set by parameters in one source file | Model check; later measurement of pressed pots |
| R2 | Even wall | Wall thickness within ±1 mm around the circumference and from pot to pot; molds self-center to within 0.5 mm | Tolerance stack and guide design; later sectioned pots |
| R3 | Pressing force and frame strength | 20 t (196 kN) rated jack; frame, pin, bolts and platen carry 1.5 times the jack rating (294 kN) without yield; deflection between the molds under 1 mm at the 10 t maximum working force, with the molds closing on a metal stop so frame stretch does not set the wall (decided by Amish, 2026-09-25) | Beam and pin calculation; later proof load |
| R4 | Throughput | Press cycle of 6 min or less with two operators, so 50 or more pots per 6 h of pressing | Cycle breakdown; later timed trial |
| R5 | Mold opening | Male mold lifts at least 30 mm clear of the female rim so the mold carriage slides out for loading and demolding; pressing stroke within one jack stroke | Kinematic layout |
| R6 | Flow-rate QC | Rack tests 4 soaked filters at once; T-gauge reads flow over 1 h to 0.1 L/h; repeatability ±0.1 L/h; acceptance band set per factory (default 1.0 to 2.5 L/h in the first hour, corrected to 25 °C; decided by Amish, 2026-09-25) | Gauge calibration by volume; later repeat tests |
| R7 | Molds made locally | Molds cast from 3D-printed patterns printed on a 250 x 250 mm class printer; finishing with hand tools and a drill press; no lathe over 300 mm swing | Pattern split and finishing review with a foundry |
| R8 | Frame built locally | Standard steel channel and plate; stick welding, drilling and bolting only; heaviest single part 40 kg or less for two-person handling | Part list and mass estimate |
| R9 | Safe operation | Fixed welded-mesh guards on the sides, back and roof and a hinged front gate enclose every pinch point of the molds, platen, jack and carriage; guard openings and their distance from moving parts prevent finger reach into the pinch zone, judged against ISO 13857; a guard-locking gate interlock stops the jack release closing (so the jack cannot be pumped to build pressure) unless the gate is shut, and keeps the gate shut while the release is closed; jack pump and release worked from outside the guard; a pin-presence interlock prevents pressing unless the load pin is fully home (pin interlock decided by Amish, 2026-09-25; guarding decided by Amish, 2026-09-26) | Hazard review and guard layout in the model; ISO 13857 desk check signed by a competent person before any force above hand pressure (decided by Amish, 2026-10-02) |
| R10 | Affordable | Press plus QC rack at or under the $1,060 value-engineering target in parts (a hypothetical control target; raised from $600 to $720 and then to $930 by Amish, 2026-09-25; topped up to $990 by Amish, 2026-09-26; raised to $1,060 by Amish, 2026-09-27) | Priced BOM (`bom/bom.csv`) |
| R11 | Footprint | Press within 1.0 x 0.7 m floor area and 2.0 m height, with the rail extension folded; QC rack within 0.8 x 0.8 m (relaxed from 0.8 x 0.5 m by Amish, 2026-09-25) | Model check |
| R12 | Product-safe materials | Faces that touch clay or test water are aluminum, food-grade polyethylene or stainless steel; no lead-based paint or oiled release agents on mold faces; molds cast from lead-free scrap (no free-machining alloys; decided by Amish, 2026-09-25) | Material list review |

*Table 2. Status against each requirement at TRL 3 (from PPR-CAL-001 v0.10 and, for R9, R10 and R11, the guarded model and BOM; least certain first).*

| ID | TRL 3 value | Status |
| --- | --- | --- |
| R9 | Guards, gate and interlocks modeled (PPR-DDR-003); fixed inner shield behind the 30 x 272 mm pump slot (2026-10-02), so the slot opens only onto the pump handle; the four guard fixes decided by Amish on 2026-10-03 modelled: 6.35 mm mesh on the front strips, lower front panel, gate and roof, small-hole plates at the release shaft and pin cable, cover plates on the top beam, covers on the crank bracket. ISO 13857 desk check rerun from the model (PPR-CAL-001, section 15): all 23 openings meet Table 4 | Met on paper. The desk check is not yet signed by a competent person, a hold point before any force above hand pressure |
| R10 | Priced BOM $1,169 (press $1,086, QC rack $83) with the constructable design (PPR-DDR-004), the pump slot shield and the guard fixes against $1,060 | **Over the value-engineering target by $109** (10.3 %) |
| R2 | Wall ±1.40 mm as cast; ±0.44 mm with molds hand-finished to templates; coaxial ±0.44 mm via match-drilled dowels | **At risk** |
| R7 | 16 flat-back pattern segments for a 250 mm printer, no core boxes; no lathe needed; cavity hand finishing unproven | **At risk** |
| R1 | Reference filter from `PARAMS` in `cad/src/model.py`: 12.30 L to the brim, 9.91 L working | Met on paper |
| R3 | No yield at 294 kN: beams 190 MPa, uprights 54 MPa, 60 mm pin 272 MPa (yield 650), M16 joint bolts 117 MPa, male flange on the stop 62 MPa. Deflection between the molds 0.66 mm at 10 t (1.97 mm at 294 kN) | Met on paper |
| R4 | 5.2 min cycle, 69 pots per 6 h | Met on paper, thin margin |
| R5 | 310 mm opening against 270 mm needed; 110 of 150 mm jack stroke | Met on paper |
| R6 | 4 stations; 0.1 L is 1.69 mm on the gauge; temperature correction to 25 °C | Met on paper; repeatability not verifiable at TRL 3 |
| R8 | Heaviest part 39.6 kg (platen); upright joints bolted, largest frame part 38.0 kg | Met on paper |
| R11 | Press 940 x 700 mm guarded with the rail extension folded (the pump handle stands 158 mm outside the right guard while in use), 1,806 mm tall; QC rack 780 x 780 mm | Met on paper, at the 0.7 m depth limit with no margin |
| R12 | Aluminum faces, polyethylene liners, HDPE buckets; lead-free scrap alloy | Met on paper |

### Requirement changes decided by Amish, 2026-09-25 (PPR-DDR-002)

- **R3:** deflection judged at the 10 t maximum working force, with the molds closing on a metal stop (was 294 kN; status not met to met on paper).
- **R10:** target raised from $720 to $930. The decided bolted joints and hinged rail extension bring the BOM to $984, so R10 was still not met; Amish topped up the budget to $990 on 2026-09-26 (see below).
- **R11:** QC rack area relaxed from 0.8 x 0.5 m to 0.8 x 0.8 m; the press footprint is judged with the hinged rail extension folded (status not met to met on paper).
- **R9 and R12:** the pin-presence interlock and lead-free scrap are now part of the requirement text.

### Requirement change decided by Amish, 2026-09-26

- **R10:** budget topped up from $930 to $990 ("I am ok with the budget top ups"; PPR-DDR-002 v0.2, item 16). The priced BOM of $984 now meets R10 on paper with a $6 (0.6 %) margin, which is thin; any price rise moves R10 back to at risk. The guarded version later the same day took the BOM to $1,051 (see below).

### Requirement change decided by Amish, 2026-09-26 (guarded version, PPR-DDR-003)

- **R9:** now states the guarding: fixed welded-mesh guards, a hinged front gate with a guard-locking interlock on the jack release, openings judged against ISO 13857, and controls outside the guard (status at risk to met on paper, with the ISO 13857 distances still an assumption).
- **R10:** the guards, gate and interlock add $67, so the BOM is $1,051 against $990 (status met on paper to not met). The budget was left unchanged that day; Amish decided the overrun on 2026-09-27 (see below).
- **R11:** the guarded press is 940 x 700 mm, exactly at the 0.7 m depth limit (status unchanged, no margin).

### Requirement change decided by Amish, 2026-09-27 (PPR-DDR-003 v0.2)

- **R10:** budget raised from $990 to $1,060 ("i agree with the budget for potpress"; option (a) in PPR-DDR-003). The priced BOM of $1,051 meets R10 on paper with a $9 (0.8 %) margin, which is thin; any price rise moves R10 back to at risk (status not met to met on paper).

### Status after the design for construction, 2026-09-30 (PPR-DDR-004)

- **R10:** the parts a build needs (steel base plate under the female mold, thicker mold flanges, dowels and bushes, floor anchors, bolted jack plate, adapter disc, interlock details) bring the BOM to $1,143 against $1,060 (status within the value-engineering target to over it by $83). The target is unchanged; the design decisions register lists the cost drivers and savings worth trying.
- No requirement text changed. R3, R8 and R11 figures are updated from PPR-CAL-001 v0.6; their status is unchanged.

### Status after the approved follow-ups, 2026-10-02 (PPR-CAL-001 v0.9)

- **R9:** the fixed inner shield behind the pump slot is designed and modelled, and the ISO 13857 desk check is done from the model's distances. The shield closes the pump slot (it opens only onto the handle and the jack's pump socket), but the check found other openings short of ISO 13857 Table 4: the 12.7 mm mesh on the front strips, lower front panel, front gate and roof is 39 to 77 mm from moving parts (80 mm needed), the release shaft and pin cable openings in the front right strip are too large for their distance, and the gap in the top beam is open from above between the parts in it. Status at risk to **not met on paper**. The changes that close these are proposed, awaiting Amish, in the design decisions register; the check is not yet signed by a competent person.
- **R10:** the shield adds $6, so the BOM is $1,149 against the $1,060 target ($83 to $89 over).
- No requirement text changed.

### Status after the guard fixes decided by Amish, 2026-10-03 (PPR-CAL-001 v0.10)

Amish, 2026-10-03: "PotPress - move forward with the four guard fixes. I accept the cost."

- **R9:** the four fixes are in the model: 6.35 mm (1/4 in) mesh with 0.9 mm wire on the front strips, lower front panel, front gate and roof; small-hole plates with a 4 mm gap round the release shaft and a 2 mm gap round the pin cable; 3 mm cover plates on the top beam from the crank bracket to the beam ends, which also close the open tops of the upright channels that the first check missed; 2 mm covers on the front and back of the crank bracket. The rerun desk check finds all 23 openings meet ISO 13857 Table 4 on paper, and no moving part touches the new parts over the full stroke, crank lift and gate travel. Status not met to **met on paper**. The check is not yet signed by a competent person; that signature remains a hold point before any force above hand pressure.
- **R10:** the fixes add $20, so the BOM is $1,169 against the $1,060 target ($89 to $109 over).
- No requirement text changed.

## Assumptions

- Pressing force needed for a well-consolidated wall is not published in the sources found (one low-cost press forms round-bottom filters with a 2 t jack, [Henry, Maley and Mehta, 2013](https://ojs.library.queensu.ca/index.php/ijsle/article/view/4532)); 5 to 10 t is assumed as the working range and the 20 t jack rating is used as the design load. Decided by Amish on 2026-10-02: every structural check stays at the full 20 t jack, and the working force is a process setting found in pressing trials with a partner factory, starting near 2 t and stepping up.
- Mix follows the RDI-C recipe reported by [Rayner (2009)](https://bdd.pseau.org/outils/ouvrages/wedc_current_practices_in_manufacturing_locally_made_ceramic_pot_filters_2009.pdf); the reference filter needs about 7.5 kg of mix per pot, below the 8 to 9.5 kg factories report (PPR-CAL-001).
- The default flow acceptance band of 1.0 to 2.5 L/h follows Nicaraguan practice and the Potters for Peace range of 1.5 to 2.5 L/h; each factory sets its own band.
- Allowable stress in structural steel is taken as 165 MPa (S275 with a factor of about 1.67).
- Guard openings: checked against ISO 13857:2019 Table 4 in the desk check of 2026-10-02, rerun with the guard fixes on 2026-10-03 (PPR-CAL-001, section 15), using straight-line distances from the model and the table as read for the check; a competent person confirms the table values and signs the check before any force above hand pressure.

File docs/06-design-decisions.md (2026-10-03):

---
doc_id: PPR-DEC-001
title: PotPress design decisions register
project: PotPress
doc_type: Design decisions register
version: "0.5"
status: Draft
date: '2026-10-03'
author: Amish Chadha
license: CERN-OHL-S-2.0
revisions:
- version: "0.1"
  date: '2026-09-30'
  author: Amish Chadha
  change: Register opened; open decisions moved out of the build plan
- version: "0.2"
  date: '2026-10-01'
  author: Amish Chadha
  change: Budget treated as a value-engineering target
- version: "0.3"
  date: '2026-10-02'
  author: Amish Chadha
  change: 'Amish approved the recommendations for all five open decisions (2026-10-02); moved to decisions made'
- version: "0.4"
  date: '2026-10-02'
  author: Amish Chadha
  change: 'Approved follow-ups carried out: four guard changes found by the ISO 13857 desk check added as open decisions; handle stroke added to the items to confirm; value engineering at USD 1,149'
- version: "0.5"
  date: '2026-10-03'
  author: Amish Chadha
  change: 'Amish decided the four guard fixes (2026-10-03); moved to decisions made; value engineering at USD 1,169'
---

# PotPress design decisions register

Every design decision still to be made, and every decision made, in one place. Each decision is argued in full in its decision record under `docs/decisions/`; this register is the index Amish works from. The build plan (`docs/05-build-plan.md`) describes the design as it stands and does not list open decisions.

## Open decisions

None. The four guard fixes found by the ISO 13857 desk check were decided by Amish on 2026-10-03 and are in the table of decisions made. The desk check, rerun with them in the model, finds every opening meets ISO 13857 Table 4 on paper (PPR-CAL-001 v0.10, section 15); it still needs a competent person's signature, which is a hold point already decided on 2026-10-02.

## To confirm when parts are bought

| # | What to confirm | Why it matters | Source |
| --- | --- | --- | --- |
| 1 | Buy the bottle jack first | Its base, release screw and pump socket set the locating blocks, the interlock coupling and the notch angle | PPR-DDR-004, Q4 |
| 2 | Mold cavity finish that releases the liner cleanly | Sets the hand finishing of both molds | PPR-DDR-004 |
| 3 | The pump handle's stroke on the jack bought, and its play in the socket | The slot and shield leave 25 mm beyond each end of the modelled stroke and 5 mm each side; a longer stroke or more play shortens those gaps | PPR-CAL-001, section 15 |

## Value engineering

Value-engineering target: USD 1,060 (a hypothetical control target, not a limit). Estimated cost of the constructable design: USD 1,169 (USD 109 over the target). Main cost drivers and savings worth trying:

- The press alone is USD 1,086 and the QC rack USD 83. The USD 1,060 target was set on 2026-09-27 to cover the whole BOM, QC rack included, so the like-for-like gap is USD 109.
- The fixed inner shield behind the pump slot (decided 2026-10-02) added USD 6. The four guard fixes (decided 2026-10-03, cost accepted by Amish) added USD 20 against the USD 15 estimated: finer mesh USD 8 (items 16 and 20), small-hole plates USD 2, top beam cover plates USD 7 (longer than estimated, to close the upright channel tops too), crank bracket covers USD 4. They are a safety requirement, so savings are sought elsewhere.
- Making the design constructable added USD 92 (PPR-DDR-004): the steel base plate under the female mold, the thicker 450 mm mold flanges, dowels and bushes (items 8 and 9, USD 44), floor anchors, the bolted jack plate and heavier feet (item 1, USD 22), the adapter disc and nut box (item 10, USD 9) and interlock details (item 21, USD 7).
- The fixed guards, front gate and interlock added USD 67 earlier (PPR-DDR-003); they are a safety requirement, so savings are sought elsewhere.
- Savings worth trying: cheaper dowels and bushes, and plywood QC rack shelves cut from offcuts.

## Decisions made

| Date | Decision | Decided by | Record |
| --- | --- | --- | --- |
| 2026-09-25 | TRL 2 review items and recommendations | Amish: "i accept all your recommendations, go with them across all repos." | PPR-DDR-001, PPR-DDR-002 |
| 2026-09-27 | Guarded version with mesh guards and an interlocked front gate; budget USD 1,060 | Amish | PPR-DDR-003 |
| 2026-09-30 | Design for construction: open-topped male mold, dowel location, M16 joints with spacer tubes, captive lead screw nut, interlock design and other changes that make the press buildable | Amish: "i accept your recommended changes on design that are currently being sent across for my approval" | PPR-DDR-004 |
| 2026-10-02 | Pump slot: keep the 30 mm slot, approved only with a fixed inner shield or tunnel behind the slot that keeps the platen and molds out of arm's reach, sized in the ISO 13857 check (item 5) | Amish: "i approve your recommendations for all 555 open decisions." | PPR-DDR-004, Q2; PPR-DDR-003 |
| 2026-10-02 | Pump handle: the 158 mm the handle stands outside the guard is operating space, like a door swing, marked on the floor layout; the 1.0 m width limit of R11 applies to the guarded box | Amish: "i approve your recommendations for all 555 open decisions." | PPR-DDR-004, Q3 |
| 2026-10-02 | Demolding: keep the tipping pins for the prototype; the potters at the first partner factory confirm the method, and if they object the pot is lifted out in its liner instead | Amish: "i approve your recommendations for all 555 open decisions." | PPR-DDR-004, Q5 |
| 2026-10-02 | Pressing force: every structural check stays at the full 20 t jack; the working force is a process setting found in pressing trials with a partner factory, starting near 2 t and stepping up | Amish: "i approve your recommendations for all 555 open decisions." | PPR-DDR-001, item 9 (as cited in the register); PPR-CAL-001, section 3 |
| 2026-10-02 | Guard openings: the ISO 13857 desk check is done now rather than at TRL 4, signed by a competent person, and is a hold point before any force above hand pressure | Amish: "i approve your recommendations for all 555 open decisions." | PPR-DDR-003; PPR-DDR-004, Q2 |
| 2026-10-03 | Front and roof mesh: 6.35 mm (1/4 in) welded mesh, 0.9 mm wire, on the front strips, lower front panel, front gate and roof (option (a)); the side and rear guards keep the 12.7 mm mesh | Amish: "PotPress - move forward with the four guard fixes. I accept the cost." | PPR-CAL-001, section 15; BOM items 16 and 20 |
| 2026-10-03 | Release shaft and pin cable openings: bolted plates behind the front right strip with a 20 mm hole round the 12 mm shaft and a 10 mm grommeted hole round the 6 mm cable (option (a)) | Amish: "PotPress - move forward with the four guard fixes. I accept the cost." | PPR-CAL-001, section 15; BOM item 16 |
| 2026-10-03 | Top beam gap: 3 mm steel cover plates bolted to the top flanges (option (a)); as modelled, one plate each side from the crank bracket to the beam end, which also closes the open tops of the upright channels | Amish: "PotPress - move forward with the four guard fixes. I accept the cost." | PPR-CAL-001, section 15; BOM item 16 |
| 2026-10-03 | Crank bracket: 2 mm sheet covers on its open front and back (option (a)); costed with the guards, BOM item 16 | Amish: "PotPress - move forward with the four guard fixes. I accept the cost." | PPR-CAL-001, section 15; BOM item 16 |

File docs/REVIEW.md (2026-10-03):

# Review note: PotPress

## Session 2026-10-03: four guard fixes made

Authority: Amish, 2026-10-03: "PotPress - move forward with the four guard fixes. I accept the cost." The four fixes were open decisions 1 to 4 in PPR-DEC-001 v0.4, proposed by the ISO 13857 desk check of 2026-10-02. `trl` and `trl_target` stay at 3. No commit or push.

### What was done

- **Model** (`cad/src/model.py`): (1) 6.35 mm (1/4 in) welded mesh, 0.9 mm wire, on the front strips, lower front panel, front gate and roof (`FINE_*` parameters, `mesh_spec()`; sides and rear keep 12.7 mm; frames sit directly behind each mesh); (2) small-hole plates behind the front right strip, a 20 mm hole round the 12 mm release shaft and a 10 mm grommeted hole round the 6 mm pin cable; (3) a 3 mm cover plate 320 x 180 mm each side of the top beam, from the crank bracket to the beam end; (4) 2 mm sheet covers on the front and back of the crank bracket (`guard_closures()`; components `opening_plates`, `beam_covers`, `bracket_covers`, all BOM 16). New checks in `--check`: `check_guard_fixes()` moves the platen over its full 110 mm travel, the male mold over its full 200 mm crank lift, the demold set-up and the pump handle stroke against the new parts, and swings the gate 0 to 105 degrees in 15 degree steps; and the ISO 13857 desk check must pass for every opening. STEP and STL re-exported. `guard_solids()` and `gate_geometry()` now take `every_wire=True` in place of `pitch=`.
- **Found while modelling:** each upright is two channels back to back whose 44 x 83 mm insides were open from above, between the beam gap openings; the v0.9 desk check missed them. The cover plates were lengthened to run over the upright tops to close them (this is why fix 3 costs $7, not about $3). The desk check now also lists the crank bracket front and back, the roof's 5 mm cut-out round the beam and the gate's 4 mm edge gaps.
- **BOM** (`bom/bom.csv`, `bom/bom-notes.md`): item 16 $73 to $90, item 20 $22 to $25, with the basis in each line (6.35 mm mesh at about $10.50/m² against $6/m², plates and covers by model mass at $1.30/kg plus bolts).
- **Documents:** PPR-CAL-001 v0.10 (section 15 rerun, sections 10, 12, 13, 14; `sizing.py` prices the fixes and prints the guard mass change); PPR-REQ-001 v0.12; PPR-PRC-001 v0.11; PPR-BLD-001 v0.6 (sections 3.10 and 3.11, steps 14 to 16, checks table); PPR-DEC-001 v0.5; README cost and desk-check sentences.
- **Drawings and pictures regenerated:** GA PPR-DWG-001 Rev P7 (isometric moved down 7 mm so the seventh revision row no longer clips it); PPR-DWG-110 Rev P3; PPR-DWG-111 Rev P2; build plan `overview.png`, `joint-06.png` (grommet plate added), `step-14.png` (plates and covers shown pulled out), `step-15.png`, `step-16.png`; concept `hero.png`, `exploded.png`, `concept-blueprint.*` (Rev P3), `model.glb` and `viewer.html`. Looked at: GA, DWG-110, DWG-111, overview, joint 6, step 14, hero and the blueprint. `cutaway.png` and `flow.png` are unchanged (guards are left out of the cutaway). The blueprint's last note line fell behind the title block on first draw (the text check did not catch it); the guard notes were merged into one line and the isometric moved below the third revision row. `step-15.png` and `step-16.png` were regenerated but not looked at. `python3 .kit/drawing.py --check-text` passes on every drawing and the blueprint; `python3 .kit/render.py` then `--check`: no FAIL.
- **Appearance model** (`cad/src/product_model.py`): the plates and covers added to the guard group; mesh drawn every wire at 12.7 mm on the sides and rear and 6.35 mm on the front, gate and roof. Render scenes re-exported to `/home/claude/renders/potpress/` (hero, exploded, lineup, gate-open, jobs). `.kit/export_views.py` cannot carry a manual camera option, so the hero's `--focus` (on the guards, handwheel, mat and person, from the 2026-10-02 render session) is still not in `potpress__jobs.json` and must be passed by hand when the hero is re-rendered on the Mac. Photoreal renders and cards are stale until then.

### Key results

- **Desk check (ISO 13857:2019 Table 4, as read), rerun for every opening:** 23 openings, **all meet on paper**. Front strips, gate, lower front and roof: 5.45 mm clear mesh needs 5 mm, nearest moving part 39 to 77 mm. Release shaft: 4 mm gap needs 2 mm, 80 mm found. Pin cable: 2 mm gap, 176 mm. Top beam gap, upright channel tops and crank bracket: covered (0 mm opening), 36 to 217 mm from moving parts. Roof cut-out 5 mm slot needs 10 mm, 72 mm found. Gate edges 4 mm, 44 mm. Side and rear mesh and the shielded pump slot unchanged (meet).
- **Motion checks:** nearest moving part 46 mm from the small-hole plates (lock rod), 55 mm from the beam covers and 35 mm from the bracket covers (stem); release shaft 4.0 mm and cable 2.0 mm all round in their holes; gate 0 overlaps over its swing, 23 mm from the folded rail extension. `model.py --check`: 55 components, 0 overlaps, 0 missing contacts, all state checks, guard fix checks and the desk check pass: **PASS**.
- **R9: not met on paper to met on paper.** The desk check is still **not signed**; the competent-person signature block is left blank, and signing stays a hold point before any force above hand pressure (S8).
- **Cost:** Value-engineering target: USD 1,060. Estimated cost of the constructable design: USD 1,169 (USD 109 over the target). The fixes add $20, against the "about USD 15" estimate Amish accepted; the $5 difference is the longer cover plates. `budget_usd` unchanged.
- **Mass:** press 344 kg unchanged; guards about 51 kg (was about 48): plates and covers +4.4 kg from the model, finer mesh -1.6 kg. Heaviest part still the platen, 39.6 kg.
- Summary: 1 over the value-engineering target (R10), 2 at risk (R2, R7), 9 met on paper.

### Proposed, awaiting Amish

None new. Note for Amish: the fixes came in $5 over the estimate he accepted (see Cost).

### Safety concerns

- The desk check is unsigned; nothing above hand pressure until a competent person signs it (S8).
- 0.9 mm wire mesh is light. The competent person should confirm it keeps its shape when pushed (ISO 14120), since the front right strip stands only 39 mm from the folding rail extension; heavier wire of the same opening would be the fallback (not proposed here).
- The top beam cover plates and crank bracket covers are removable guards held by bolts; the build plan says to remove them only with the press at rest and the release open.

### Recommended next step

A competent person reviews and signs the desk check; render the hero, lineup and gate-open views on the Mac (hero with `--focus`).

## Session 2026-10-02: Photoreal renders redone on the constructable design

Amish, 2026-10-02: "Photoreal renders are out of date in most repos ... COMPLETE THESE". Rendered with Blender Cycles on Amish's Mac (batch F1) from the scenes exported from `cad/src/product_model.py`, captioned with `.kit/photo_caption.py`; `media/card.png` and `media/social-preview.png` regenerated with `.kit/cards.py`. Each raw render was looked at once. No commit or push; `trl` unchanged.

- Views: `media/render-hero.png`, `media/render-exploded.png`, `media/render-lineup.png`, `media/render-gate-open.png`.
- Re-renders: hero (twice), lineup and gate-open. The mannequin stood at the front right, in line with the hero camera, and hid most of the press and the pump handle; in the lineup it stood in front of the press's right side. `cad/src/product_model.py` now stands it at the front left facing the press (clear of the open gate by at least 0.2 m) and extends the floor slab to suit; the hero note says "1.75 m person at the front left for scale". The hero was then re-rendered with `--focus` on the guards, handwheel, mat and person, because the larger slab left most of the frame empty. `.kit/export_views.py` does not carry `--focus`, so a re-render of the hero needs it passed by hand.
- Appearance deviations already logged (2026-10-02, render only): mesh drawn at every wire; coiled springs with hooks; jack split into red body and polished ram; nameplate and load rating label; hazard label; floor slab, anti-fatigue mat and 1.75 m mannequin (now at the front left rather than the front right); floor anchors left out.
- `python3 .kit/image_qc.py`: 6 images, 0 problems. `python3 .kit/render.py --check`: no FAIL, no storefront warning.
- The "Stale, to regenerate on Amish's Mac (Blender)" note (2026-09-30 session) is removed; this work resolves it.

## Session 2026-10-02: approved follow-ups carried out

Authority: Amish, 2026-10-02: "497 follow-up actions that need CAD, drawing, picture, BOM or calculation work ... APPROVED CHANGES, COMPLETE THESE", and "Photoreal renders are out of date in most repos ... COMPLETE THESE" (render scenes prepared here; the renders themselves are made on Amish's Mac). Follow-ups from the 2026-10-02 list below and `/home/claude/review/applied/potpress.json`. `trl` and `trl_target` stay at 3. No commit or push.

### Approved follow-ups carried out

| # | Follow-up | Done | Where |
| --- | --- | --- | --- |
| 1 | Design the fixed inner shield behind the 30 mm pump slot; check the handle clears it over its stroke | Done. A tunnel of 2 mm folded sheet, 30 mm wide inside, along the handle's line from the slot to 3 mm off the jack body, with a 3 mm flange bolted through the slot frame and a 30 x 6 mm stay to the base beam (2.8 kg). Sized in the desk check: the slot is lengthened from 220 to 272 mm (174 to 446 mm up) and the tunnel's roof and floor follow the handle, so the handle stops 25 mm short of them and of the slot ends at both ends of its stroke (ISO 13854 finger gap); 5 mm to the side walls; 2.3 mm past the slot frame. Constructability checks PASS (52 components, no overlaps, all 49 contacts, open and demold states, handle stroke, hooks, lock notch); new checks for the shield's contacts, side clearance and stroke-end gaps | `cad/src/model.py` (`pump_shield`, `HANDLE_STROKE`, `guard_solids`), STEP and STL re-exported |
| 1 | Add the shield to the GA and the right side guard sketch | Done | PPR-DWG-001 Rev P6; PPR-DWG-110 Rev P2 |
| 1 | Show the shield in the build plan guard section, item 3 | Done: section 3.10 items 3 and 6, Figure 20 (joint 11, shield cut along the handle), steps 14 and 16 | `docs/05-build-plan.md` v0.5; `docs/05-build-plan/joint-11.png`, `step-14.png`, `step-16.png`, `overview.png` |
| 1 | Add the shield to BOM line 16 | Done: $67 to $73 (2.8 kg x $1.30/kg plus $2 bolts); brush strip dropped | `bom/bom.csv`, `bom/bom-notes.md` |
| 1 | Re-judge R9 once the shield is modelled | Done: R9 **at risk to not met on paper** (see below) | PPR-CAL-001 v0.9, PPR-REQ-001 v0.11 |
| 2 | Mark the pump handle's 158 mm operating space on a floor layout | Done: outlined on the floor beside the right guard in the GA (159 x 122 mm zone) and noted in the build plan workspace | PPR-DWG-001 Rev P6; PPR-BLD-001 section 7 |
| 4 | Mean pressure at 2 t in PPR-CAL-001 Table 3 | Done: 19.6 kN, 0.21 MPa, the starting reference for pressing trials | PPR-CAL-001 v0.9 section 3; `sizing.py` |
| 5 | ISO 13857 desk check of the mesh, pump slot, roof reach and the handle's pass by the slot frame, signed by a competent person | Desk check done from the model's distances (`model.py --iso`, printed by `sizing.py`), every guard opening included. **Not signed**: a competent person must review it against the published table and sign; the signature block is left blank | PPR-CAL-001 v0.9 section 15 |

### Key results

- **Desk check (ISO 13857:2019 Table 4, as read):** side and rear mesh 100 to 110 mm from moving parts (80 needed): meets. Pump slot: opens only into the shield; no moving part enters it in any position: meets. Handle past the slot frame: 2.3 mm, a gap too small for a fingertip: meets on paper. **Does not meet:** front right strip 39 mm, front gate 44 mm, lower front panel 45 mm, front left strip 60 mm (all to the folding rail extension, which moves with the platen), roof mesh 77 mm (stem); release shaft opening (16 mm gaps, 120 needed, 61 found) and pin cable opening (40 mm square, 200 needed, 166 found); the top beam gap is open from above (104 x 150 and 104 x 60 mm openings) and reaches the stem and, cranked up, the male flange 15 mm under the beam; above the roof, the stem cap rises to 10 mm under the crank bracket top in a bracket open front and back.
- **Requirement status changes:** R9 at risk to **not met on paper**. R10 stays over the value-engineering target, now by $89. Summary: 1 over the target (R10), 1 not met on paper (R9), 2 at risk (R2, R7), 8 met on paper.
- **Cost:** Value-engineering target: USD 1,060. Estimated cost of the constructable design: USD 1,149 (USD 89 over the target). `budget_usd` unchanged.
- **Mass:** press 344 kg unchanged; guards about 48 kg with the 2.8 kg shield (was about 45 kg); heaviest part still the platen at 39.6 kg.

### Proposed, awaiting Amish

Added as open decisions 1 to 4 in the design decisions register (PPR-DEC-001 v0.4), from the desk check: (1) 6.35 mm (1/4 in) mesh on the front strips, lower front panel, gate and roof; (2) small-hole plates at the release shaft and pin cable openings; (3) cover plates over the top beam gap; (4) covers on the front and back of the crank bracket. About USD 15 together (estimate). With all four, every opening meets Table 4 on paper. The handle's real stroke and play on the jack bought is added to "To confirm when parts are bought".

Appearance model deviations from `model.py` (render only): guard and gate mesh drawn at every wire (12.7 mm) instead of every 8th; coiled springs with hooks in place of the spring envelopes; jack split into a red body and a polished ram; nameplate and load rating label on the top beam; hazard label on the front right strip; floor slab, anti-fatigue mat and a 1.75 m mannequin standing to the front right; floor anchors left out (below the floor).

### Documents changed and new versions

- `docs/04-calcs/01-sizing.md` PPR-CAL-001 v0.9 and `docs/04-calcs/sizing.py`
- `docs/03-requirements.md` PPR-REQ-001 v0.11
- `docs/02-concept.md` PPR-PRC-001 v0.10
- `docs/06-design-decisions.md` PPR-DEC-001 v0.4
- `docs/decisions/0004-design-for-construction.md` PPR-DDR-004 v0.5
- `docs/05-build-plan.md` PPR-BLD-001 v0.5
- `bom/bom.csv`, `bom/bom-notes.md`, `README.md`
- `cad/src/model.py`, `sheets.py`, `build_plan_media.py`, `concept_media.py`, `product_model.py` (rebuilt from the constructable components)

### Pictures regenerated (each looked at)

GA PPR-DWG-001 Rev P6 (notes shortened to fit above the title block); making sketch PPR-DWG-110 Rev P2; build plan `overview.png`, `joint-11.png` (redrawn as a cut through the shield), `step-14.png` (shield shown pulled out to the right), `step-15.png` to `step-18.png`; concept `hero.png`, `cutaway.png`, `exploded.png` (guard line renamed so its legend no longer runs into the picture), `concept-blueprint.*` (Rev P2: force from trials at 2 t, shield), `model.glb` and `viewer.html`. `python3 .kit/drawing.py --check-text` passes on every drawing and the blueprint. No "pictures not yet updated" notes remained to remove.

### Render scenes

`cad/src/product_model.py` rebuilt from `model.components()` so every dimension is the constructable model's. Exported with `.kit/export_views.py` to `/home/claude/renders/potpress/`: `potpress__hero`, `__exploded`, `__lineup`, `__gate-open` (.npz and .json each) and `potpress__jobs.json`. Photoreal renders, `card.png` and `social-preview.png` are still the concept's until they are rendered on Amish's Mac.

### Cross-repo actions

None.

### Safety concerns

- The desk check is unsigned and finds openings short of ISO 13857; nothing above hand pressure until the proposed guard changes are made and a competent person signs the check (build plan safety stop S8).
- The folding rail extension, which moves with the platen, is the part nearest the front guards; this was not visible in the earlier "105 to 110 mm" figures.

### Recommended next step

Amish to decide open decisions 1 to 4; then model the chosen guard changes, re-run the desk check, and render on the Mac.

## Session 2026-10-02: open decisions decided by Amish

Authority: Amish, 2026-10-02: "i approve your recommendations for all 555 open decisions." The recommendations approved are those written for the five open decisions in the design decisions register (PPR-DEC-001). No model, BOM quantity or price, or picture was changed; where a decision needs one, it is listed below as a follow-up. `trl` and `trl_target` stay at 3. No commit or push.

### Decisions recorded

Five, all moved to "Decisions made" in `docs/06-design-decisions.md`, dated 2026-10-02:

1. Pump slot: keep 30 mm, approved only with a fixed inner shield or tunnel behind the slot, sized in the ISO 13857 check.
2. Pump handle: the 158 mm it stands outside the guard is operating space, marked on the floor layout; R11 applies to the guarded box.
3. Demolding: keep the tipping pins for the prototype; the first partner factory's potters confirm the method, with lifting out in the liner as the fallback.
4. Pressing force: structural checks stay at the full 20 t jack; the working force is found in pressing trials from about 2 t upward.
5. ISO 13857: desk check done now, signed by a competent person, a hold point before any force above hand pressure.

### Documents changed

- `docs/06-design-decisions.md` (PPR-DEC-001 v0.3)
- `docs/decisions/0004-design-for-construction.md` (PPR-DDR-004 v0.4): Q2, Q3 and Q5 recorded as decided; status stays Draft
- `docs/decisions/0003-guarded-version.md` (PPR-DDR-003 v0.3): ISO 13857 check decided
- `docs/02-concept.md` (PPR-PRC-001 v0.9)
- `docs/03-requirements.md` (PPR-REQ-001 v0.10): R9 now at risk until the pump slot shield is designed and the check is signed
- `docs/04-calcs/01-sizing.md` (PPR-CAL-001 v0.8): R9 status and summary count; force text

### Follow-up actions to carry approved decisions into the design

1. Decision 1 (model, drawings, build plan pictures, BOM): design the fixed inner shield or tunnel behind the 30 mm pump slot in `cad/src/model.py`, check that the pump handle still clears it over its stroke, add it to the GA drawing PPR-DWG-001, the right side guard sketch and the build plan pictures (section on the guards, step 3), and add it to BOM line 16.
2. Decision 1 (calcs): once the shield is modelled, re-judge R9 in PPR-CAL-001 and PPR-REQ-001.
3. Decision 2 (drawings): mark the pump handle's 158 mm operating space on a floor layout (GA drawing or build plan overview).
4. Decision 4 (calcs): add the mean pressure at 2 t to PPR-CAL-001, Table 3, so the pressing trials have a starting reference.
5. Decision 5 (calcs): do the ISO 13857 desk check of the mesh, the pump slot, the roof reach and the pump handle's 1.4 to 2 mm pass by the slot frame from the model's distances, and have a competent person sign it.

### Points found in the review

- Value engineering does not compare like with like: the USD 1,060 target was set on 2026-09-27 to cover the USD 1,051 BOM including the QC rack, so reading it against the press alone hides the real USD 83 gap.
- Decision 4 cites PPR-DDR-001 item 9, which is the first co-design partner, not the pressing force. The partner decision is still open (REVIEW 2026-09-30) but is missing from the open decisions table; it was not part of the decisions approved on 2026-10-02 and should be added back to the register.
- The pump handle runs 1.4 to 2 mm from the slot frame over its stroke; that is a finger shear point and should be covered by the ISO 13857 check (follow-up 5). A brush strip does not count as a guard.
- PPR-DDR-004 Q2 deferred the ISO 13857 check to TRL 4, while build plan safety stop S8 required it before any force. Decision 5 resolves this in favor of S8: the check is done now.
- PPR-DDR-004 Q4 (the interlock notch angle, set to the jack bought) remains proposed in that record; it is covered by "To confirm when parts are bought", item 1.

## Session 2026-09-30: constructable design and illustrated build plan (/build-plan)

Authority: the `/build-plan` command and Amish's instructions of 2026-09-30 ("Design concept and constructability are different states"; "fix the design assumptions to match and be physically feasible as you draw the illustrations"; "i accept your recommended changes on design that are currently being sent across for my approval"). This replaces the earlier text-only build plan and its review section, which Amish rejected. Commit and push were skipped by instruction. `trl` and `trl_target` stay at 3.

### What was done

- `cad/src/model.py`: design made constructable (P1 to P17 below). New checks with `python cad/src/model.py --check`: no overlaps among 51 components with the press closed, open (platen down, stem cranked up, pin parked) and set for demolding (extension out, carriage on the tipping pins, gate open); all 47 required contacts touch; the pump handle clears the guard over its whole stroke (1.4 mm nearest at the stroke ends); the carriage hooks meet the tipping pins (1.0 mm sliding fit); the lock rod drops into the disc notch. Result: PASS.
- `docs/decisions/0004-design-for-construction.md` (PPR-DDR-004 v0.2): every change with its reason; accepted by Amish 2026-09-30; Table 3 holds what stays proposed.
- `docs/04-calcs/sizing.py` and `01-sizing.md` (PPR-CAL-001 v0.6): new checks (male flange on the stop, M16 joints, rails over the platen gap, pin block with screw hole, tipped mold, stop lugs, tipping pins); masses, deflection and costs from the constructable model.
- `docs/03-requirements.md` (PPR-REQ-001 v0.8): status from CAL v0.6; no requirement text changed.
- `bom/bom.csv`: lines rewritten to the buildable parts (anchors, studs, jack plate, M16 10.9 bolts, spacer tubes, shims, steel base plate, dowels, bushes, adapter disc, captive nut, lift handles, tipping pins, interlock parts); total $1,143.
- `cad/src/build_plan_media.py` (new) and `docs/05-build-plan.md` (PPR-BLD-001 v0.2, rewritten from the template): overview, 14 making sketches `cad/drawings/PPR-DWG-101` to `114`, 11 joint close-ups and 18 assembly steps in `docs/05-build-plan/`, all drawn from the model and each looked at.
- `cad/src/sheets.py`: GA PPR-DWG-001 regenerated at Rev P5. STEP and STL re-exported.
- `cad/src/concept_media.py`: restructured so each picture renders in its own process (the full run had been killed for memory); cutaway leaves out the guards and gate. `media/hero.png`, `cutaway.png`, `exploded.png`, `flow.png`, `concept-blueprint.*`, `model.glb` (now about 12 MB) and `viewer.html` regenerated and checked.
- `.kit/build_views.py`: `overview()` gained a `key=True` option (numbered bubbles on the parts and a key column, in place of leader lines that crossed the picture with 19 parts). Proposed for the kit.
- `project.yaml`: `design_state: constructable`; PPR-DDR-004 added to `trl_evidence`. `README.md`: "Building the prototype" section with the overview picture; key components and concept figures updated.

### Design changes made for construction (PPR-DDR-004)

1. **P1 male mold:** open-topped plug, its inside a drafted cone that forms its own sand core; flat-back pattern, no core box.
2. **P2 male flange:** 45 mm thick, 450 mm across; the stem's 190 mm disc bears on the plug floor (bedded in epoxy putty, 4 x M12); 62 MPa at 294 kN on the stop (was about 487 MPa).
3. **P3 mold location:** two 16 mm dowels and two steel bushes, drilled with the molds clamped on 15 mm printed wall spacers; stop faces lapped on float glass; patterns with 1.3 % shrink, 3 mm lapping allowance and 2 degree draft; female cup bedded and screwed on a 15 mm steel base plate. No lathe.
4. **P4 jack and slot:** jack turned 25 degrees to the right front; slot on the handle's line, widened from 25 to 30 mm; handle clears spring and upright by about 50 mm.
5. **P5 lead screw:** captive nut with 8 mm float; press force through the pin only.
6. **P6 beam gap:** 104 mm with 2 mm shims.
7. **P7 joint bolts:** 4 x M16 10.9 per joint, 22 mm edge distance, 25 x 3 spacer tubes; 117 MPa double shear at 294 kN.
8. **P8 tipping:** tipping pins on the extension, hooks and retaining pins on the carriage, lift handles.
9. **P9 interlock:** lock disc, lock rod, gate slider, pin slider and plunger round the jack's release screw.
10. **P10 feet and BOM:** feet web up with studs and anchor tubes, four floor anchors, spring lugs, tubes and shims in the BOM; QC pot shelf raised to 720 mm (35 mm clear of the buckets).
11. **P11 (found):** rail hinge moved back from 320 to 290 mm so the folded extension clears the gate and lower panel with the platen down.
12. **P12 (found):** 28 mm hole down the pin block so the fixed lead screw passes when the stem is cranked up.
13. **P13 (found):** plastic guide strips on the top beam webs; stem play front to back 7 to 1 mm.
14. **P14 (found):** pump handle (20 mm, 700 mm) added to the design and checked over its stroke.
15. **P15 (found):** assembly order set by the model (stem in before the top beam; both molds together on the extension).
16. **P16 (found):** female base plate on greased steel rails, not plastic strips; rails checked over the platen gap (101 MPa).
17. **P17 (found):** lift handles behind the tipping pins (the only handle was in front of them).

### Key results

| Quantity | Value |
| --- | --- |
| Constructability checks | PASS: closed, open and demolding positions; handle stroke; hooks; lock notch |
| Frame at 294 kN | Beams 190 MPa, pin 272 MPa (yield 650), M16 joints 117 MPa, male flange 62 MPa (cast yield about 90) |
| Deflection at 10 t | 0.66 mm (R3 met on paper) |
| Masses | Press 344 kg plus about 45 kg of guards; heaviest part the platen at 39.6 kg (R8, 40 kg) |
| Parts cost | Estimated $1,143 against the $1,060 value-engineering target: **over the target by $83** (7.8 %) |
| Requirements | 1 over the value-engineering target (R10), 2 at risk (R2, R7), 9 met on paper |

### Proposed, awaiting Amish (PPR-DDR-004, Table 3)

1. **Value engineering:** the estimate is $83 over the $1,060 target; the savings worth trying are in the design decisions register. `budget_usd` is unchanged.
2. **Q2 pump slot 30 mm:** same ISO 13857 band as 25 mm; the ISO 13857 check itself is still open (PPR-DDR-003).
3. **Q3 pump handle:** stands 158 mm outside the right guard while in use (beyond R11's 1.0 m width). Recommendation: treat it as operating space.
4. **Q4 interlock notch angle:** set to the jack bought, at TRL 4.
5. **Q5 demolding by tipping:** confirm with a partner factory's potters.

Still open from earlier sessions: the ISO 13857 guard distance check and the first co-design partner (PPR-DDR-001 item 9).

### Safety concerns

- The build plan's safety stops cover welding, galvanised mesh, lifts up to 40 kg, standing the frame, and the only unguarded jack movement (step 13, by hand to first contact with the pin home). Nothing authorises pressing or any force above hand pressure.
- The single load pin still carries the whole press force; the pin-presence interlock is now detailed (plunger, cable, pin slider) but untested.
- The slot widening (Q2) and the handle outside the guard (Q3) touch the guarding and need Amish's decision and the ISO 13857 check.

### TRL

`trl` stays 3, now with a constructable design and an illustrated build plan. **TRL 4 remains on hold by Amish's instruction.** No build, purchase, measurement or test was started.

### Recommended next step

Amish to decide Q1 to Q5, then regenerate the photoreal renders from an updated appearance model on the Mac. After that, the repo is ready for a TRL 4 recommendation when Amish lifts the hold.

## Session 2026-09-27: owner decision applied

Authority: Amish wrote on 2026-09-27, "i agree with the budget for potpress." This applies recommendation (a) of item 1 in the 2026-09-26 session below: raise the budget to about $1,060 for the guarded version. Decided by Amish on 2026-09-27. Only this item is decided. `trl` and `trl_target` stay at 3.

### What changed

- `project.yaml`: `budget_usd` from 990 to 1060, with the history comment extended ("raised to 1,060 by Amish, 2026-09-27 (PPR-DDR-003)").
- `docs/decisions/0003-guarded-version.md` PPR-DDR-003 v0.2: the cost overrun is recorded as decided by Amish on 2026-09-27 (option (a)); status line updated; the ISO 13857 guard opening check is marked proposed, awaiting Amish.
- `docs/04-calcs/01-sizing.md` PPR-CAL-001 v0.5: summary, decisions table, cost section, Table 10 (R10 now met on paper) and a v0.5 change note. `sizing.py` needed no change; it reads the budget from `project.yaml` and now prints a $9 (0.8 %) margin.
- `docs/03-requirements.md` PPR-REQ-001 v0.7: R10 target $1,060, Table 2 status, new "Requirement change decided by Amish, 2026-09-27" subsection.
- `docs/02-concept.md` PPR-PRC-001 v0.7: summary, numbers table and "Budget $1,060" design choice.
- `docs/01-problem.md` PPR-PRB-001 v0.6: budget constraint $1,060.
- `bom/bom-notes.md` and `README.md`: budget and R10 lines. `bom/bom.csv` is unchanged.
- `cad/src/sheets.py`: PPR-DWG-001 Rev P4 ("Budget raised to $1,060 (DDR-003); R10 met; note only"); the cost note now reads "Cost $1,051 vs $1,060 budget: R10 met on paper"; the isometric view moved down 9 mm and shrank slightly so it clears the taller revision table. `cad/drawings/PPR-DWG-001.svg`, `.pdf`, `.png` regenerated and checked.
- `docs/pdf/`: rebuilt with `python .kit/render.py` (PRB v0.6, PRC v0.7, REQ v0.7, CAL v0.5, DDR-003 v0.2).
- No change to `cad/src/model.py` or `cad/src/product_model.py`: the decision is a budget figure only, so no geometry, dimension or interface changed. STEP, STL and concept media were not regenerated because nothing they show changed.

### Result

| Quantity | Value |
| --- | --- |
| Cost | $1,051 (press $970, QC rack $81) against $1,060 |
| R10 | Met on paper, $9 (0.8 %) margin; thin, any price rise moves it back to at risk |
| Requirements | 0 not met, 2 at risk (R2, R7), 10 met on paper |

### Photoreal renders

The decision does not require regenerating the renders: no part in any RENDER_VIEWS view changed shape, size or position. Separately, item 2 of the 2026-09-26 session still stands: `media/render-*.png` show the unguarded press and need re-rendering from the guarded RENDER_VIEWS before any public use.

### Still proposed, awaiting Amish

1. **ISO 13857 guard distances.** The adequacy of the 11 mm mesh at about 105 to 110 mm, the 25 mm pump slot and reach over the roof remains a stated assumption, not checked (PPR-DDR-003).
2. **Photoreal renders** re-rendered for the guarded press (2026-09-26 item 2).
3. **First co-design partner** (item 9): still open.

### TRL

`trl` stays 3. **TRL 4 remains on hold by Amish's instruction.** No build, measurement or purchasing was started.

## Session 2026-09-26: guarded version

Authority: Amish wrote on 2026-09-26, "for pot press build a guarded version and make sure the render follows." Recorded as decided in `docs/decisions/0003-guarded-version.md` (PPR-DDR-003 v0.1). No existing part or main dimension changed. `trl` and `trl_target` stay at 3.

### What changed

- `cad/src/model.py`: new guard parameters and helpers (`mesh_panel`, `angle_frame`, `guard_layout`, `gate_geometry`, `interlock_geometry`) and three new parts: fixed mesh guards (BOM 16), front gate (20), gate interlock and release valve extension (21). `press_only()` now includes them, so `cad/step/potpress-press.step`, `potpress-assembly.step` and the STLs are the guarded press. Mesh is drawn at every eighth wire (101.6 mm) so views stay readable.
- Guarding chosen: fixed welded-mesh guards (sides, back, roof, front strips, lower front panel) and a hinged front gate with a mechanical guard-locking interlock on the jack release. A hand pump has no power to switch, so the interlock holds the release valve open (pumping then builds no pressure) unless the gate is shut, and holds the gate shut while the valve is closed. The decided pin-presence plunger acts on the same lock bar. Two-hand control (does not suit a one-lever pump) and hold-to-run alone (leaves a hand free) were rejected; see PPR-DDR-003.
- `bom/bom.csv`: item 16 is now the fixed guards ($67, was a $55 allowance for all guarding); new item 20, front gate with hinges ($21); new item 21, gate interlock and release extension with the pin-presence plunger ($34). `bom/bom-notes.md` updated.
- `docs/04-calcs/sizing.py`: items 20 and 21 counted as press cost; guard solids left out of the mass table (their mesh is symbolic). The masses and tipping result are unchanged. PPR-CAL-001 moved to v0.4 with the guarded costs.
- `docs/02-concept.md` PPR-PRC-001 v0.6 and `docs/03-requirements.md` PPR-REQ-001 v0.6: guarding, safety, R9 text and status tables.
- `cad/src/sheets.py`: PPR-DWG-001 Rev P3, "Guards and interlocked front gate added"; notes condensed so they fit.
- `cad/src/concept_media.py` re-run: `media/hero.png`, `cutaway.png`, `exploded.png`, `flow.png`, `concept-blueprint.*`, `model.glb` now show the guarded press.
- `cad/src/product_model.py`: guard frames in safety-yellow powder coat, mesh wire by wire at 12.7 mm pitch, pump slot with brush strip, standoffs, hazard label, red guard-locking interlock with link rod, lock block, release extension and T-handle; gate in group `gate_closed` and, swung open 105 degrees, in `gate_open`. RENDER_VIEWS: hero and lineup now include the guards with the gate closed (hero note replaced); exploded keeps its parts and now says guards are not shown; new view `gate-open` (el 18, az -68). Triangles: hero and gate-open 683k, lineup 725k, exploded 612k. All 88 parts valid.
- `project.yaml`: PPR-DDR-003 added to the TRL evidence. Budget unchanged.

### Numbers

| Quantity | Value |
| --- | --- |
| Mesh | 12.7 x 12.7 x 1.6 mm welded (about 11 mm clear); 4.3 m² fixed plus 0.57 m² gate |
| Nearest moving part behind the mesh | Back 105 mm (platen deck), sides 109 mm (platen sleeves), front 110 mm (carriage handle) |
| Guarded press | 940 x 700 x 1,806 mm with the rail extension folded (840 x 655 mm unguarded) |
| Guard mass | About 45 kg (estimate) |
| Cost | $1,051 (press $970, QC rack $81) against $990: $61 (6.2 %) over |

### Requirements now

| ID | Status |
| --- | --- |
| R10 | **Not met**: $1,051 against $990 |
| R2, R7 | At risk (unchanged) |
| R9 | Met on paper; guard openings and distances assumed against ISO 13857, tables not checked |
| R11 | Met on paper at the 0.7 m depth limit, no margin |
| R1, R3 to R6, R8, R12 | Met on paper (unchanged) |

### Proposed, awaiting Amish

1. **Cost overrun ($61).** Options: (a) raise `budget_usd` to about $1,060, since guarding is a safety requirement (recommended); (b) cost the QC rack ($81) outside the press budget; (c) keep $990 and record R10 as not met. `budget_usd` was not changed.
2. **Photoreal renders.** `media/render-hero.png`, `render-exploded.png` and `render-lineup.png` still show the unguarded press; they need re-rendering from the updated RENDER_VIEWS (including the new `gate-open` view) before any public use.
3. Done later in this session: `README.md` and PPR-CAL-001 (now v0.4, "Guarded version costs (PPR-DDR-003)") were updated to the $1,051 guarded BOM.
4. First co-design partner (item 9): still open.

### Safety concerns

- The ISO 13857 adequacy of the 11 mm mesh at about 105 mm, the 25 mm pump slot and reach over the roof is an assumption; a competent person must check it before any use.
- The gate-open render draws the press in its pressing position for comparison; in use the gate opens only after the release is open and the platen is down.
- Guards and interlocks must be inspected each shift and never defeated. All other concerns from earlier sessions stand.

### TRL 4

**TRL 4 remains on hold by Amish's instruction.** No build, guard check, measurement or purchasing was started.

### Recommended next step

Amish to decide the cost overrun (item 1). Then re-render the product views.

## Session 2026-09-25: recommendations accepted

Authority: Amish wrote on 2026-09-25, "i accept all your recommendations, go with them across all repos." Every item with a recommendation is now **Decided by Amish, 2026-09-25: go with recommendation** (recorded in `docs/decisions/0002-recommendations-accepted.md`, PPR-DDR-002 v0.1, and in PPR-DDR-001 v0.2). `project.yaml` keeps `trl: 3` and `trl_target: 3`.

### Decisions applied and what changed

| # | Decision | Before | After |
| --- | --- | --- | --- |
| 10 | R3 judged at the 10 t working force, molds closing on a metal stop | Under 1 mm at 294 kN: 1.84 mm, not met | Under 1 mm at 10 t: 0.61 mm, met on paper (stop face already modeled) |
| 11 | R11 rack 0.8 x 0.8 m, hinged front rail extension | Rack limit 0.8 x 0.5 m, not met; press 970 mm deep | Rack 780 x 780 mm fits; rails fixed to 320 mm with a 330 mm folding extension, press 840 x 655 mm; met on paper |
| 12 | Upright joints bolted, 4 x M20 8.8 each | Welded frame 147 kg in one piece; R8 at risk | 16 bolts modeled; 75 MPa shear, 123 MPa bearing at 294 kN; largest frame part 37.4 kg; R8 met on paper |
| 13 | One 60 mm pin with a pin-presence interlock | Interlock "switch or blocking plate" | Mechanical pin-presence interlock on the jack release (BOM item 16, R9 text) |
| 14 | Raise the budget | `budget_usd` $720 | `budget_usd` $930 |
| 15 | Lead-free scrap for the molds | Proposed | In R12 and the PPR-PRB-001 constraints |

Files changed: `project.yaml` (budget, evidence list); `README.md` (numbers, components, four new write-up sections); `docs/01-problem.md` v0.4; `docs/02-concept.md` v0.4; `docs/03-requirements.md` v0.4; `docs/04-calcs/01-sizing.md` v0.2 and `sizing.py` (bolt bearing, hinge moment, folded envelope, bolt and hinge costs); `docs/decisions/0001-trl2-review-decisions.md` v0.2; new `docs/decisions/0002-recommendations-accepted.md`; `cad/src/model.py` (joint bolts, hinged rail extension) with STEP and STL re-exported; `cad/src/sheets.py` and PPR-DWG-001 at Rev P2; `cad/src/concept_media.py` and all `media/` regenerated; `bom/bom.csv` (items 2, 7, 8, 9, 16) and `bom/bom-notes.md`; all PDFs in `docs/pdf/` re-rendered.

Cost: items 2 ($77 to $124, joint bolts) and 7 ($34 to $45, hinges and lugs) take the BOM from $926 to **$984**, $54 (6 %) over the new $930 budget.

### Requirements now (not met first)

| ID | Status |
| --- | --- |
| R10 | **Not met**: $984 against $930 |
| R2, R7, R9 | At risk (wall evenness depends on hand finishing; cavity finishing without a lathe unproven; guards and interlocks not modeled) |
| R1, R3, R4, R5, R6, R8, R11, R12 | Met on paper |

Summary: 1 not met, 3 at risk, 8 met on paper (was 3, 4 and 5).

### Still awaiting Amish

1. First co-design partner (item 9): no recommendation; stays "Proposed, awaiting Amish".
2. Decided by Amish, 2026-09-26: budget top-up to $990 (option a). Remaining cost gap (new item 16): $984 against $930. Options: (a) raise `budget_usd` to about $990 (recommended, since the added cost is the joints and hinges just decided); (b) cost the QC rack ($81) outside the press budget; (c) keep $930 and record R10 as not met.

### Cross-repo actions

None. No decision here needs a change in another repo.

### TRL 4

**TRL 4 remains on hold by Amish's instruction.** No build, proof load test, bolt torque check, measurement, trial or purchasing was started.

### Write-up and media

- README now has "Concept rationale", "Burning platform" (WHO and UNICEF JMP 2025, WHO drinking-water fact sheet, Brown et al. 2008, IntechOpen press costs), "Where it could be used" and "What sparked the idea" (Ron Rivera's tire-jack clay press and filter mold for Potters for Peace, Nicaragua).
- All generated files (docs PDFs, PPR-DWG-001, `media/`) were regenerated so they carry designmolecule.com.

### Safety concerns

- Unchanged from the TRL 3 session, plus: check the bolted upright joints for tightness before each shift; keep fingers clear of the rail extension hinges and deploy it only onto its stop lugs.

## Session 2026-09-25: TRL 3

Authority: Amish wrote on 2026-09-25, "proceed with all of your recommendations across all batches. Make sure we don't proceed to TRL 4 on any of them." `project.yaml` now shows `trl: 3` and `trl_target: 3`. **TRL 4 is on hold by Amish's instruction.**

### What was done

- `docs/decisions/0001-trl2-review-decisions.md` (PPR-DDR-001 v0.1): TRL 2 items 1 to 8 recorded as decided by Amish, 2026-09-25: go with recommendation; item 9 and new items 10 to 15 left open.
- `docs/04-calcs/01-sizing.md` (PPR-CAL-001 v0.1) and `docs/04-calcs/sizing.py`: geometry, mix and masses, pressure, frame, pin, welds, mold shells, deflection chain, travel, jack, crank, cycle, alignment stack, patterns, QC gauge and temperature correction, masses from the model, tipping, cost, and a results table for R1 to R12. The script reads `cad/src/model.py` and `bom/bom.csv` and prints every quoted number.
- `cad/src/model.py`: parametric build123d model (filter, shell molds with locating lip and flash groove, UPN channel frame, platen with sleeves, rails and carriage, stem, 60 mm pin, lead screw and handwheel, 2 x 2 QC rack). Exports `cad/step/potpress-assembly.step`, `potpress-press.step`, `female-mold.step`, `male-mold.step`, `filter-pot.step`, `t-gauge.step` and matching STLs in `cad/stl/`.
- `cad/src/sheets.py` and `cad/drawings/PPR-DWG-001.svg`, `.pdf`, `.png`: general arrangement at Rev P1, 1:20, marked "CONCEPT, NOT FOR FABRICATION" and "PRELIMINARY, NOT FOR FABRICATION". The concept sheet keeps PPR-DWG-010.
- `bom/bom.csv`: 19 lines, all priced with supplier types, total $926; `bom/bom-notes.md` updated.
- `cad/src/concept_media.py` now builds from the model and the calc; all media in `media/` regenerated and checked; temporary `media/_views*` folders deleted.
- `docs/01-problem.md`, `docs/02-concept.md`, `docs/03-requirements.md` moved to v0.3; `README.md` updated; `project.yaml` set to TRL 3 with the evidence list and `budget_usd: 720`.

### Requirements at TRL 3 (not met first)

| ID | Result | Status |
| --- | --- | --- |
| R3 | Strength met (beams 190 MPa, pin 258 MPa of 650, uprights 54 MPa at 294 kN); deflection between molds 1.84 mm at 294 kN against 1 mm (0.61 mm at 10 t) | **Not met** |
| R10 | $926 against $720 (press $845, QC rack $81) | **Not met**, 29 % over |
| R11 | Four 345 mm rims need a 780 x 780 mm rack against 0.8 x 0.5 m; press frame 840 x 640 mm but 970 mm deep with the fixed rail extension | **Not met** |
| R2 | Wall ±1.40 mm as cast; ±0.43 mm if hand-finished to templates | At risk |
| R7 | 16 pattern segments on a 250 mm printer; finishing without a lathe unproven | At risk |
| R8 | Heaviest part 38.9 kg as fabricated, but the welded frame is 147 kg in one piece | At risk |
| R9 | Guards and interlocks only in the BOM, not modeled | At risk |
| R1, R4, R5, R6, R12 | Filter geometry from one file; 5.2 min cycle and 69 pots per 6 h; 310 mm opening against 270 mm; 1.69 mm per 0.1 L; product-safe faces | Met on paper |

TRL 2 errors corrected: the single UPN 100 base (about 1,071 MPa), the two 30 mm pins (about 1,034 MPa in bending), solid molds (would be 57 and 41 kg), the four-station rack in 800 x 440 mm (cannot fit), press mass 180 kg (now 298 kg) and cost $716 (now $926).

### Decisions recorded

Decided by Amish, 2026-09-25: go with recommendation (PPR-DDR-001): jack below; crank lift with a load pin and a standard jack; cast aluminum molds from printed patterns (concrete-backed variant documented only); welded frame; slide-out and tilt demolding; manual QC rack and T-gauge; default band 1.0 to 2.5 L/h corrected to 25 °C; `budget_usd` raised to $720.

### Proposed, awaiting Amish (status updated in the session "recommendations accepted")

1. First co-design partner (item 9): left open under the portfolio rule; no choice made. Still proposed, awaiting Amish.
2. Decided by Amish, 2026-09-25: go with recommendation. R3: judge deflection at the 10 t working force with the molds closing on a metal stop (recommended), rather than at 294 kN.
3. Decided by Amish, 2026-09-25: go with recommendation. R11: allow 0.8 x 0.8 m for the 2 x 2 QC rack (recommended); also a hinged front rail extension for the press depth.
4. Decided by Amish, 2026-09-25: go with recommendation. Frame joints: bolt the four upright joints (4 x M20 8.8 each) so no part exceeds 40 kg (recommended).
5. Decided by Amish, 2026-09-25: go with recommendation. Load pin: one 60 mm 42CrMo4 pin with a pin-presence interlock (recommended, as modeled) or two pins at two stations.
6. Decided by Amish, 2026-09-25: go with recommendation. Cost gap of $206: raise `budget_usd` to about $930 (recommended), or cost the QC rack separately and build the concrete-backed molds first.
7. Decided by Amish, 2026-09-25: go with recommendation. Scrap aluminum must be lead-free (recommended) or new A356 ingot.

### Safety concerns

- The single load pin carries the whole press force; a missing or half-inserted pin ejects the male mold. The pin-presence interlock is essential, not optional.
- Guards, gate and interlocks are BOM lines, not yet modeled or designed (R9 at risk).
- The press is about 298 kg with its center of mass about 0.8 m up; about 740 N at 1 m tips it forward. Anchor it.
- Handwheel at about 1.8 m: awkward overhead cranking; the self-locking screw holds the mold if released.
- Lead in scrap aluminum could contaminate a drinking-water product; specify lead-free scrap.
- Silica dust, silver compounds and kiln heat in the same workshop; a passing flow test is not proof of pathogen removal.
- All strengths are paper values; a proof load test by a competent person is needed before any use, and that is TRL 4 work.

### Citations

- Henry, Maley and Mehta, "Designing a Low-Cost Ceramic Water Filter Press", *IJSLE* 8 (1), 2013: checked this session through a public PDF copy. It confirms the $2,300 Potters Without Borders press (over $3,000 with labor), a target under $200 built by two people in two days, and a 2 t car jack for round-bottom filters. The journal page itself blocks automated fetching.
- CMWG (2011) best practice recommendations: title confirmed by web search, but the PDF returned HTTP 403, so it is still cited for scope only, not for specific numbers. Flag kept.

### Existing TRL 4 material

None found. `build-log/README.md` is the scaffold header only; `electronics/` and `firmware/` are empty. Nothing was added to them.

### Recommended next step

Amish to decide items 2 to 7 above (and the partner when the area is ready), after which the requirement and cost changes can be folded into v0.4 of the documents at TRL 3. **TRL 4 is on hold by Amish's instruction.** For reference only, TRL 4 would need: a built press and molds, a proof load test to 294 kN with the pin interlock working, measured mold gap deflection and wall thickness on sectioned pots, a timed cycle trial, T-gauge calibration by volume, a test report (TST) with `environment: lab` and build log entries. None of this should start without a new instruction.

## Session 2026-09-25: /populate to a strong TRL 2 (overnight batch run)

### What was done

- `docs/01-problem.md` (PPR-PRB-001 v0.2): the problem with sourced facts (JMP 2025, Potters for Peace, the Cambodia trial and lab study, press costs from the Nigerian and Penn State presses, production parameters, factory QC practice), users and context, constraints, out of scope, prior work with links, open questions, and a co-design checklist (none existed before; the portfolio's standard checklist was added and tailored to a filter factory).
- `docs/03-requirements.md` (PPR-REQ-001 v0.2): 12 measurable requirements (R1 to R12) with targets and planned verification, and a status table against the concept.
- `docs/02-concept.md` (PPR-PRC-001 v0.2): how it works, components numbered to the BOM and exploded view, first-order numbers (geometry and charge, force and pressure, travel and cycle, flow QC, cost) with assumptions, design choices, safety and open questions.
- `cad/src/concept_media.py`: massing model of the press (base, uprights, top beam, jack, platen, springs, carriage, female and male molds, male mold slide, pressed pot) and the QC rack (rack, test pots, T-gauge, buckets), with the 1.75 m scale figure.
- `media/`: `hero.png`, `concept-blueprint.png`, `.pdf` and `.svg`, `cutaway.png`, `exploded.png` with BOM callouts, `flow.png` (material flow per filter, all values marked as estimates), `model.glb` and `viewer.html`.
- `bom/bom.csv`: 19 lines with indicative prices, items 1 to 14 numbered to match the exploded view; `bom/bom-notes.md` updated.
- `README.md`: hero image and links line added before "## Problem"; problem, concept, key components and safety updated to match.
- `docs/pdf/`: branded PDFs of the three controlled documents.
- `project.yaml`: unchanged. The pitch and problem still match what was found.

### Key results (estimates, to be checked at TRL 3)

| Quantity | Estimate | Requirement |
| --- | --- | --- |
| Reference filter | 280 mm inner rim, 240 mm deep, 15 mm wall; about 10 L working volume | R1 met on paper |
| Charge and pot mass | about 8.0 kg mix; about 7.3 kg pressed, about 4.2 kg fired | |
| Mean pressure | about 0.5 to 1.1 MPa at 5 to 10 t; 2.1 MPa at 20 t | Working force assumed, not sourced |
| Frame at 1.5 x jack rating (294 kN) | top beam about 190 MPa, uprights about 54 MPa, pins about 104 MPa | R3 met on paper; deflection unchecked |
| Opening travel | about 270 mm needed; jack gives about 150 mm | R5 **at risk**; crank lift proposed |
| Cycle and output | about 5 min; about 70 pots per 6 h of pressing | R4 met, thin margin |
| Flow gauge | 1.0 L is about 16 mm of level drop; 0.1 L about 1.6 mm | R6 met, resolution tight |
| Size and mass | press about 920 x 640 x 1,655 mm, about 180 kg | R8 and R11 met |
| Parts cost | about $716 (press about $645, QC rack about $71) | R10 **not met**, about 19 % over |

Requirements not met or at risk: **R10 (cost) is not met.** R2 (even wall) is at risk until the mold alignment is designed; R5 (opening travel) is at risk until the lift and jack are chosen; R7 (molds made locally without a large lathe) is at risk because cavity finishing is unproven.

### Proposed, awaiting Amish (items 1 to 8 since decided; see PPR-DDR-001)

1. Decided by Amish, 2026-09-25: go with recommendation. **Architecture:** jack below lifting the female mold against a fixed male mold (recommended), versus an inverted-rated jack pushing down, or a screw press.
2. Decided by Amish, 2026-09-25: go with recommendation. **Male mold lift:** hand crank with load pins and a standard jack (recommended), versus a 20 t long-stroke cylinder with hand pump (about $150 to $250 more), versus a counterweighted lever.
3. Decided by Amish, 2026-09-25: go with recommendation. **Mold material:** cast aluminum from printed patterns (recommended), with printed shells backed by fiber-reinforced concrete built as a low-cost variant (about $115 cheaper, durability unknown).
4. Decided by Amish, 2026-09-25: go with recommendation. **Frame:** welded (recommended), with a bolted variant documented later.
5. Decided by Amish, 2026-09-25: go with recommendation. **Demolding:** slide-out carriage that tilts to turn the pot onto a board (recommended), versus air-assisted release or leaving the pot on the male mold.
6. Decided by Amish, 2026-09-25: go with recommendation. **QC:** manual rack and printed T-gauge (recommended); load-cell logger per station as a later option.
7. Decided by Amish, 2026-09-25: go with recommendation. **Default acceptance band:** 1.0 to 2.5 L/h in the first hour, corrected to 25 °C, adjustable per factory.
8. Decided by Amish, 2026-09-25: go with recommendation. **Budget:** (a) raise `budget_usd` from $600 to about $720; (b) keep $600 and adopt the concrete-backed molds for the first prototype (about $600); (c) keep $600 for the press only and cost the QC rack separately (the press alone is about $645, still over). Recommendation: (a), because the aluminum molds are the part of the design most likely to work first time. `project.yaml` is unchanged at $600.
9. Still proposed, awaiting Amish (no recommendation adopted under the portfolio rule). **First partner:** an existing filter factory in the Potters for Peace network, an NGO planning a new factory, or a university ceramics lab. Recommendation: an existing factory, since it can tell us the pressing force and acceptance band.

### Safety concerns

- Crushing at the molds, platen and carriage rails; guards, an interlocked gate and pump controls outside the guard are in the BOM but not yet designed.
- Load pins must be fully home before pressing; a sheared or walked-out pin can eject. A pin-presence interlock should be considered at TRL 3.
- Heavy molds (about 12 and 20 kg) and a tall 180 kg frame: tipping and dropped loads.
- Workshop hazards outside PotPress but near it: silica dust from clay and husk ash, silver nitrate, kiln heat.
- A passing flow test is not proof of pathogen removal; the documents say so and must keep saying so.

### Gaps and notes

- The pressing force needed for a good wall was not found in the sources reviewed; the 5 to 10 t working range is an assumption.
- The CMWG best practice PDF and the Penn State paper could not be opened from this session, so they are cited for scope only, not for specific numbers.

### Suggestions (not added to the repo)

- A parametric generator that outputs the pattern segments and the T-gauge scale from one filter definition would make the "printable mold geometry" in the pitch concrete at TRL 3.

### Recommended next step

Review this note and the media. If approved, run `/advance-trl3` to size the frame, pins and guides by calculation, settle the lift and jack choice, split and check the casting patterns, and produce the parametric model and drawing sheet.

## Session 2026-09-26: sources strengthened
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

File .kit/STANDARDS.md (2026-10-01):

---
doc_id: OHP-STD-001
title: Documentation and drawing standard
project: Open Hardware Portfolio
doc_type: Standard
version: "1.7"
status: Released
date: 2026-09-30
author: Amish Chadha
license: CC-BY-SA-4.0
revisions:
  - version: "1.0"
    date: 2026-09-24
    author: Amish Chadha
    change: First release of the standard
  - version: "1.1"
    date: 2026-09-24
    author: Amish Chadha
    change: Adopt Technology Readiness Levels (section 9) for project maturity
  - version: "1.2"
    date: 2026-09-24
    author: Amish Chadha
    change: Portfolio phase cap (section 10), concept media standard (section 11), CLAUDE.md guardrails
  - version: "1.3"
    date: 2026-09-24
    author: Amish Chadha
    change: Scale figure, interactive 3D viewer and flow diagrams added to concept media; session slash commands
  - version: "1.4"
    date: 2026-09-26
    author: Amish Chadha
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

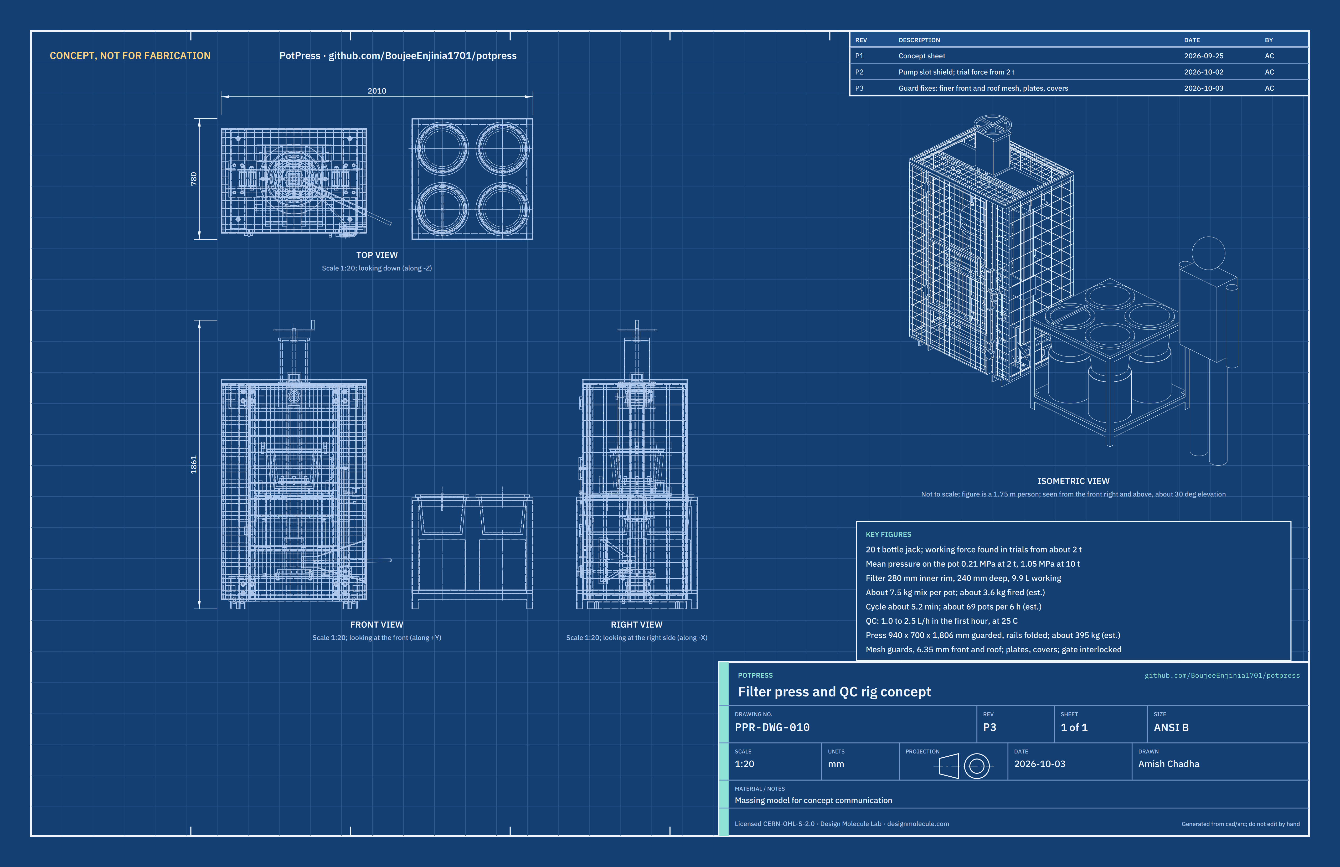
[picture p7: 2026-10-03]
media/concept-blueprint.png

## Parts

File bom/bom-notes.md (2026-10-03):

# BOM notes

Prices are indicative 2026 estimates for regional small-town suppliers, derived in PPR-CAL-001 (`python docs/04-calcs/sizing.py`) from the model masses: steel at $1.30/kg, cast aluminum at 1.35 kg poured per kg of casting and $2.00/kg scrap plus a $1.50/kg foundry fee, and PLA at $20/kg. Bought items are regional retail estimates. They are not quotes. Item numbers match the exploded view (`media/exploded.png`). Items 15 and 17 to 19 are not modeled. Items 16, 20 and 21 are the guarded version decided by Amish on 2026-09-26 (PPR-DDR-003): guard steel is priced at $1.30/kg, galvanized welded mesh at about $6/m² for the 12.7 mm mesh and about $10.50/m² for the 6.35 mm mesh (estimate, 2026-10-03), and hinges, springs and cable as regional retail estimates.

Item 11, the pressed filter pot, is the product. It is listed so the numbering matches the exploded view and is priced at $0.

| Group | Items | Cost |
| --- | --- | --- |
| Press | 1 to 10, 15 to 18, 20, 21 | $1,086 |
| QC rack | 12 to 14, 19 | $83 |
| **Total** | all | **$1,169** |

Value-engineering target: USD 1,060. Estimated cost of the constructable design: USD 1,169 (USD 109 over the target). The target is the hypothetical control target in `project.yaml` (`budget_usd`), not a spending limit; the design decisions register (PPR-DEC-001) lists the cost drivers and the savings worth trying.

Changes on 2026-10-03: the four guard fixes from the ISO 13857 desk check, decided by Amish on 2026-10-03 ("move forward with the four guard fixes. I accept the cost."). Item 16 goes from $73 to $90: 6.35 mm (1/4 in) welded mesh with 0.9 mm wire on the front strips, lower front panel and roof (1.1 m², the price difference from the 12.7 mm mesh, $5); two small-hole plates behind the front right strip with a 20 mm hole round the release shaft and a 10 mm grommeted hole round the pin cable ($2); two 3 mm cover plates on the top beam from the crank bracket to the beam ends, which also close the open tops of the upright channels ($7); and 2 mm sheet covers on the front and back of the crank bracket ($4). Item 20 goes from $22 to $25 for the 6.35 mm mesh on the gate (0.61 m²). The plates and covers are priced by their mass in the model at $1.30/kg plus their bolts. Together the fixes add $20, against the "about USD 15" estimate in the register; the cover plates cost more than estimated because they now also cover the upright channel tops. The total goes from $1,149 to $1,169. The guards, gate and interlock now weigh about 51 kg (estimate): the plates and covers add 4.4 kg from the model and the finer mesh is 1.6 kg lighter than the mesh it replaces.

Changes on 2026-10-02: item 16 gains the fixed inner shield behind the pump slot that Amish decided on 2026-10-02 (a 2 mm folded sheet tunnel with a flange and a stay, 2.8 kg from the model at $1.30/kg plus $2 for bolts, $6), and the slot is lengthened to 272 mm so each end stands 25 mm beyond the handle at the ends of its stroke. The brush strip is dropped; the shield is the guard. Item 16 goes from $67 to $73 and the total from $1,143 to $1,149. The guards, gate and interlock weigh about 48 kg with the shield (estimate; the model draws the mesh at every eighth wire).

Earlier changes: the constructable design (PPR-DDR-004, 2026-09-30) took the total from $1,051 to $1,143 (steel base plate under the female mold, thicker mold flanges, dowels and bushes, floor anchors, bolted jack plate and heavier feet, adapter disc and nut box, interlock details). The guarded version (PPR-DDR-003, 2026-09-26) took it from $984 to $1,051. Mold scrap must be lead-free (decided, PPR-DDR-001 item 15), and item 21 includes the decided pin-presence interlock (PPR-DDR-001 item 13).

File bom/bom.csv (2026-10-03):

item | qty | spec | supplier | unit_cost_usd | make_buy | notes
1 Base beam feet and jack plate | 1 | Two UPN 160 channels 840 mm with a 104 mm gap between webs and 10 mm end blocks; two spring anchor lugs 150 x 30 x 8 mm; 240 x 234 x 20 mm jack plate bolted across the top flanges with 4 x M12 and three locating blocks; two UPN 100 feet 640 mm lying web up, each with two welded-in 26.9 mm anchor tubes and four M12 studs; 4 x M12 floor anchors 80 mm into concrete; S275; about 58 kg | Local steel stockist (sections and plate); hardware store (anchors and bolts) | 88.00 | make | PPR-CAL-001 mass x $1.30/kg plus anchors and bolts; design for construction PPR-DDR-004
2 Upright pair with joint bolts | 2 | Two UPN 100 channels back to back (100 x 100 mm) 1,401 mm long; bolted to both beams with 4 x M16 x 150 grade 10.9 bolts, nuts and hardened washers per joint (8 per pair) at 28 mm from the web; eight 25 x 3 mm spacer tubes 83 mm long inside the channels; 2 mm shim packs 100 x 120 mm each side of each joint; S275; about 29 kg per pair plus about 2.6 kg of bolts | Local steel stockist (sections); fastener supplier (10.9 bolts) | 64.00 | make | M16 10.9 in double shear 117 MPa at 294 kN; edge distance 22 mm; bolted joints decided by Amish 2026-09-25 (PPR-DDR-001 item 12; PPR-DDR-002); M16 and spacers PPR-DDR-004
3 Top crossbeam with pin doublers | 1 | Two UPN 160 channels 840 mm with a 104 mm gap and 10 mm end blocks, 12 mm web doublers 200 x 139 mm at the pin, 62 mm pin bore, 4 x 14 mm holes for the crank bracket; UHMW-PE stem guides: two side blocks 29 x 104 x 160 mm and two 6 mm strips on the webs with 62 mm pin holes; S275; about 39 kg | Local steel stockist (sections and plate); plastics supplier (UHMW-PE) | 57.00 | make | 190 MPa at 294 kN; front and back guide strips added PPR-DDR-004
4 20 t bottle jack | 1 | 20 t hydraulic bottle jack, about 150 mm stroke, about 60 mm ram, screw extension, release valve screw on the same side as the pump socket, base about 160 mm square; pump handle about 20 mm diameter and at least 700 mm long (or a 20 mm tube extension); about 13 kg | Hardware or automotive tool store | 60.00 | buy | Regional retail estimate; 110 mm of stroke used; turned 25 degrees so the handle and release point to the right front (PPR-DDR-004)
5 Moving platen with guide sleeves | 1 | Two UPN 140 channels 479 mm, 479 x 440 x 6 mm deck, 200 x 104 x 20 mm jack pad, two 10 mm plate guide sleeves 150 mm tall round the uprights (1 mm clearance), two spring anchor lugs 160 x 30 x 8 mm; about 40 kg | Local steel stockist (sections and plate) | 51.00 | make | PPR-CAL-001 mass x $1.30/kg; 98 MPa at 294 kN
6 Return springs | 2 | Tension springs, about 300 N each, free length under 250 mm, stretched to about 360 mm between hook ends with the platen up, with hooks | Hardware store | 5.00 | buy | Gravity alone returns the platen; springs keep it seated on the ram
7 Rails hinged extension and mold carriage | 1 | Four 30 x 15 mm flat-bar rails at 60 and 170 mm each side of the axis, fixed to 290 mm in front of the axis; a 335 mm extension on two weld-on barrel hinges with 20 x 30 mm stop lugs that folds down when not demolding, with two 12 mm bright steel (EN8 or 1045) tipping pins; back end stop; carriage ring of 25 x 12 mm flat bar with pull handle, side lips, two tipping hooks, two lift handles and two 10 mm retaining pins; rails greased; about 22 kg | Local fabrication shop; hardware store (hinges) | 41.00 | make | Folding keeps the press inside its guards (R11; PPR-DDR-002); hinge line moved back 30 mm and tipping hooks and handles added (PPR-DDR-004)
8 Female mold | 1 | Sand-cast aluminum-silicon cup 450 mm flange x 40 mm, 20 mm shell, 15 mm floor, rim counterbore, flash groove, flat-back pattern (no core); stop face lapped flat; bedded on and screwed to a 350 x 350 x 15 mm S275 base plate with 4 x M8 countersunk screws; two 16 mm hardened dowel pins pressed in at 202 mm radius; about 36.5 kg with its plate | Local aluminum foundry (sand casting); local steel stockist (plate); bearing supplier (dowels) | 119.00 | make | Casting 22 kg x 1.35 poured x $2.00/kg scrap plus $1.50/kg foundry fee; plate and pins; scrap must be lead-free (for example cast wheels or pistons; no free-machining bar) decided by Amish 2026-09-25 (PPR-DDR-001 item 15); PPR-DDR-004
9 Male mold | 1 | Sand-cast aluminum-silicon plug open at the top (flat-back pattern, the inside forms its own sand core), 15 mm shell, 30 mm tip, 450 mm flange x 45 mm; stop face lapped flat; two 22 mm steel bushes for the 16 mm dowels, drilled with the molds clamped together; 4 x M12 tapped holes in the tip floor; about 23 kg | Local aluminum foundry (sand casting); bearing supplier (bushes) | 102.00 | make | Same basis as item 8; flange 62 MPa at 294 kN on the stop (PPR-CAL-001; PPR-DDR-004)
10 Male mold slide and crank | 1 | SHS 90 x 90 x 8 stem 670 mm on a 190 x 20 mm adapter disc (bedded in epoxy putty on the plug floor and held by 4 x M12), pin block 74 x 74 x 120 mm with a 28 mm screw hole, captive nut box with 8 mm float, cap plate; one 60 mm load pin in 42CrMo4 quenched and tempered with head, pull knob and R-clip (about 4.5 kg); crank bracket from 10 and 15 mm plate bolted to the top beam with 4 x M12; Tr24 x 5 lead screw about 360 mm with nut, two thrust collars and a 260 mm handwheel; about 45 kg | Local steel stockist; bearing and transmission supplier (lead screw and nut) | 101.00 | make | Steel about $40 plus pin bar $15 plus screw and nut $25 plus handwheel $12; the screw only lifts: the nut floats 8 mm so press force goes through the pin (PPR-DDR-004)
11 Pressed filter pot | 1 | Product: reference filter, about 7.5 kg of mix | Filter factory (product) | 0.00 | make | Shown for context; the product is not a press cost
12 QC flow-test rack | 1 | 2 x 2 station rack 780 x 780 x 720 mm: 40 x 40 x 4 steel angle legs and edge frames, 18 mm plywood pot shelf at 720 mm with four 316 mm holes, bucket shelf at 120 mm | Local fabrication shop; timber merchant | 47.00 | make | About 30 kg; pot shelf raised so the hanging pots clear the buckets by 35 mm (PPR-DDR-004); rack area misses R11 (PPR-CAL-001)
13 Printed T-gauge | 4 | PETG dipstick, 340 mm crossbar, 100 mm scale in liters generated from the filter geometry (1.0 L is about 16.7 mm) | Maker space or university 3D printer | 2.00 | make | About 55 g each
14 Collection bucket | 4 | 20 L food-grade HDPE bucket, about 300 mm diameter and no more than 330 mm tall | Market | 4.00 | buy | Regional retail estimate
15 Printed casting patterns | 1 | PLA flat-back patterns for items 8 and 9: 1.3 % shrink allowance, 3 mm machining allowance on the stop faces and the female base, 2 degree draft on the flange rims, 8 segments each for a 250 mm printer (about 5.4 kg of filament), sealed and waxed | Maker space or university 3D printer; filament supplier | 118.00 | make | 5.4 kg x $20/kg plus $10 sealer and wax; no core boxes needed (PPR-DDR-004)
16 Fixed mesh guards and pump slot shield | 1 | Galvanized welded mesh on 25 x 25 x 3 angle frames: 12.7 x 12.7 x 1.6 mm (1/2 in, about 11 mm clear) on the two side guards and the rear guard (3.1 m2); 6.35 x 6.35 x 0.9 mm (1/4 in, about 5.5 mm clear) on the two front strips (the right one set back 40 mm for the interlock), the lower front panel and the roof guard round the top beam (1.1 m2); 24 m of angle (about 27 kg); eight flat-bar standoffs to the beam webs; framed 30 x 272 mm pump handle slot in the right side guard, its ends 25 mm beyond the handle at the ends of its stroke; fixed inner shield behind the slot: a tunnel of 2 mm folded steel sheet, 30 mm clear inside, round the handle's path from the slot to 3 mm off the jack body, with a 3 mm flange bolted through the slot frame with 4 x M8 and a 30 x 6 mm flat-bar stay bolted to the base beam (about 2.8 kg); guard fixes of 2026-10-03: two 3 mm plates behind the front right strip, bolted through the mesh with 6 x M5, with a 20 mm hole round the 12 mm release shaft and a 10 mm grommeted hole round the 6 mm pin cable (0.13 kg); two 3 mm cover plates 320 x 180 mm on the top beam's top flanges from the crank bracket to the beam ends, over the beam gap and the upright tops, 8 x M8 into tapped flanges (2.7 kg); two 2 mm sheet covers 170 x 285 mm on the front and back of the crank bracket, 8 x M6 into the side plate edges (1.5 kg); M8 bolts at the panel corners | Local fabrication shop (shield folded on a press brake; plates and covers cut from sheet); hardware store (mesh) | 90.00 | make | Mesh $26 at about $6/m2 plus angle $35 at $1.30/kg plus standoffs and slot $6; shield 2.8 kg x $1.30/kg plus $2 for bolts, $6 (PPR-CAL-001); guard fixes decided by Amish 2026-10-03 (PPR-DEC-001), $17: 1.1 m2 of 6.35 mm mesh at about $10.50/m2 instead of $6/m2 ($5), small-hole plates by mass plus 6 x M5 and a grommet ($2), cover plates 2.7 kg x $1.30/kg plus 8 x M8 and tapping ($7), bracket covers 1.5 kg x $1.30/kg plus 8 x M6 ($4); guarded version decided by Amish 2026-09-26 (PPR-DDR-003); slot moved and widened (PPR-DDR-004); shield decided by Amish 2026-10-02 (PPR-DEC-001); every opening checked in the ISO 13857 desk check (PPR-CAL-001 section 15); no brush strip
17 Release liners and trim tool | 1 | Food-grade polyethylene liner sheets, wire trim tool, sponge | Market | 10.00 | buy | Not modeled
18 Fasteners consumables and finish | 1 | M8 guard bolts, rubber pads, welding electrodes (about 5 kg E6013), grinding discs, steel-filled epoxy putty for bedding the molds, lead-free primer and paint (not on mold faces) | Hardware store | 45.00 | buy | Not modeled
19 QC timer and thermometer | 1 | Kitchen timer and a 0 to 50 C thermometer for the water temperature correction | Market | 12.00 | buy | Not modeled
20 Front gate with hinges | 1 | Hinged front gate 572 x 1063 mm: 20 x 20 x 2 square tube frame with mid rail, 6.35 x 6.35 x 0.9 mm galvanized welded mesh (1/4 in, about 5.5 mm clear; 0.61 m2), two weld-on lift-off hinges on the left front post, pull handle and a 6 mm tongue plate with a 14 mm hole | Local fabrication shop; hardware store (hinges) | 25.00 | make | Opens outward to the left; PPR-DDR-003; widened and tongue added (PPR-DDR-004); 6.35 mm mesh decided by Amish 2026-10-03 (PPR-DEC-001), 0.61 m2 at about $10.50/m2 instead of $6/m2, +$3
21 Gate interlock and release valve extension | 1 | Mechanical interlock round the jack's release valve: coupling on the valve screw, 12 mm release shaft with two universal joints, 80 mm lock disc with one notch and a front knob; 12 mm lock rod with lift handle and collar on a 20 x 8 mm post with guide tabs; gate slider and pin slider with return springs; pin-presence plunger over the load pin head with a push-pull cable to the pin slider. The release can be closed only with the gate shut and the pin home, and the gate cannot open while the release is closed | Local fabrication shop; hardware store (universal joints; springs; push-pull cable) | 41.00 | make | No electrics; PPR-DDR-003; detailed in PPR-DDR-004

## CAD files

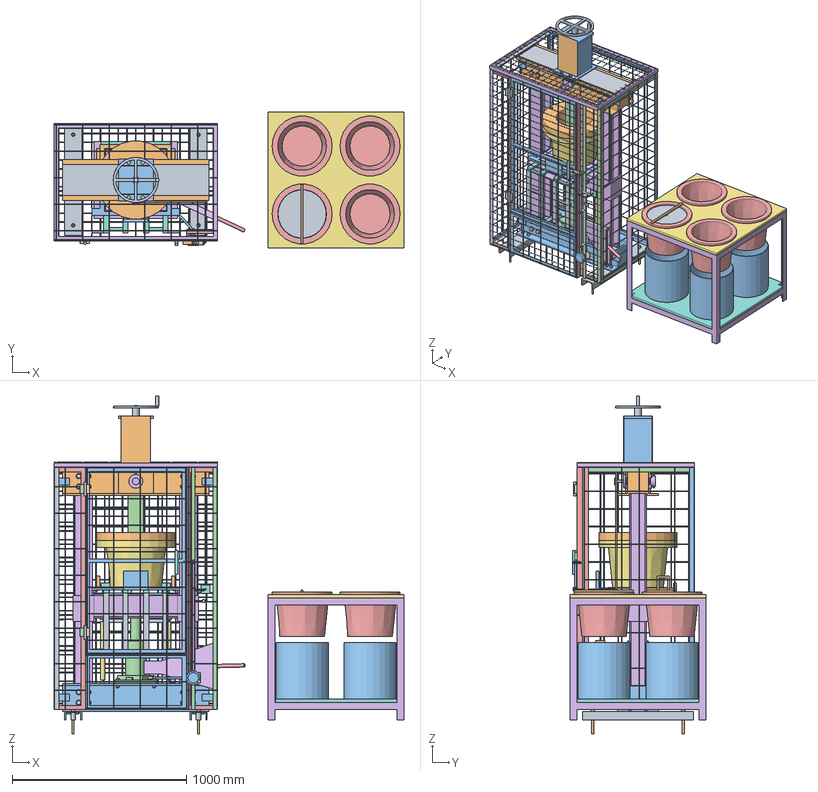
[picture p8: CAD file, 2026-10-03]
cad/step/potpress-assembly.step
2010.0 x 780.0 x 1941.0 mm

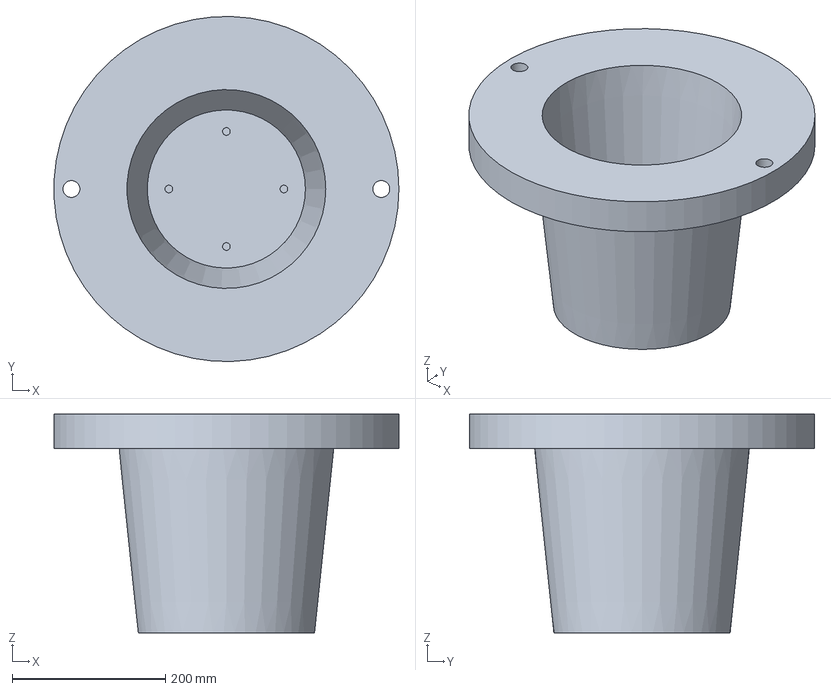
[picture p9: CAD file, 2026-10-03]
cad/step/male-mold.step
449.7 x 449.8 x 285.0 mm

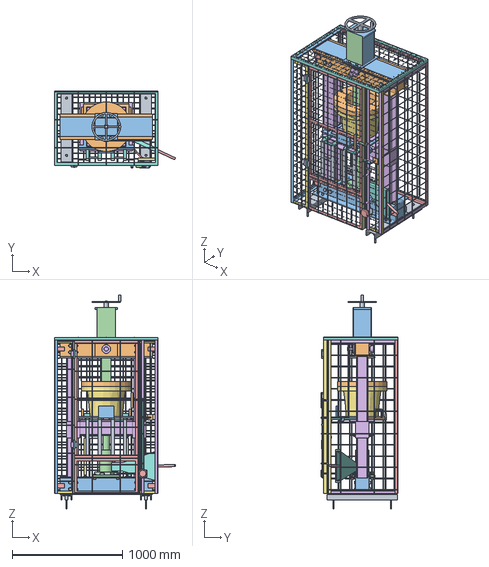
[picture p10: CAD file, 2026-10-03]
cad/step/potpress-press.step
1098.3 x 700.0 x 1941.0 mm

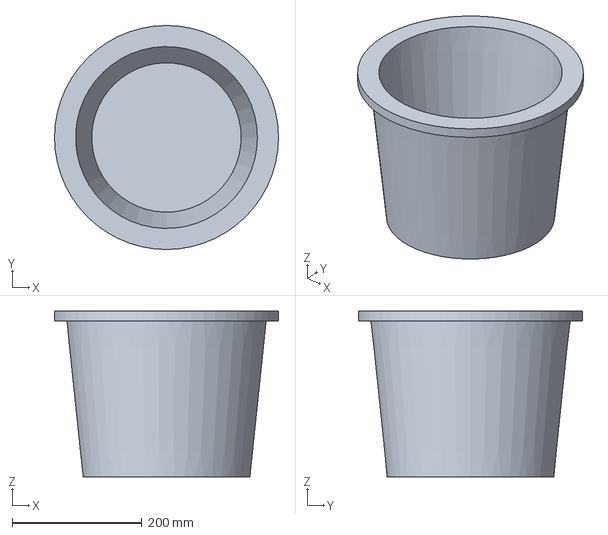
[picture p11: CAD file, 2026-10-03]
cad/step/filter-pot.step
345.0 x 345.0 x 255.0 mm

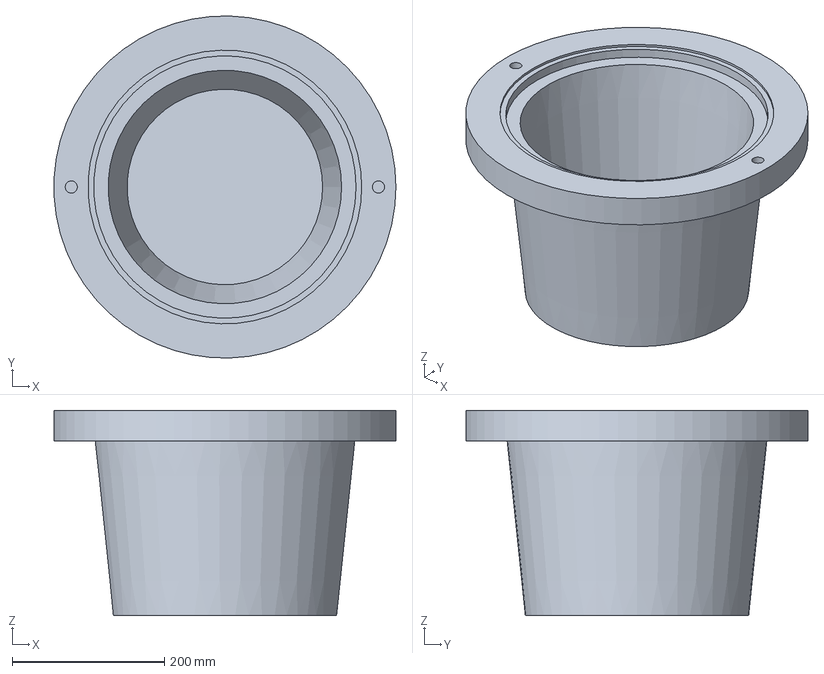
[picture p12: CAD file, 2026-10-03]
cad/step/female-mold.step
449.7 x 449.8 x 270.0 mm

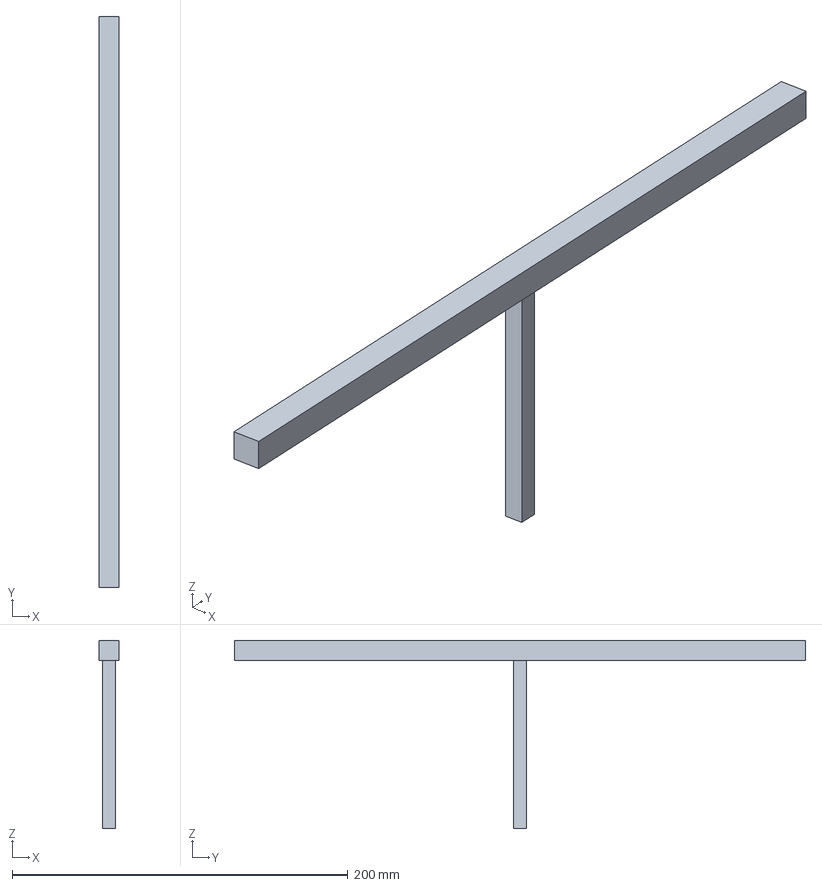
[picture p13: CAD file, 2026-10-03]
cad/step/t-gauge.step
12.0 x 340.0 x 112.0 mm

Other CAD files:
cad/stl/female-mold.stl
cad/stl/filter-pot.stl
cad/stl/male-mold.stl
cad/stl/potpress-press.stl
cad/stl/t-gauge.stl

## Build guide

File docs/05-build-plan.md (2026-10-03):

---
doc_id: PPR-BLD-001
title: PotPress prototype build plan
project: PotPress
doc_type: Build plan
version: "0.6"
status: Draft
date: '2026-10-03'
author: Amish Chadha
license: CERN-OHL-S-2.0
revisions:
- version: "0.1"
  date: '2026-09-30'
  author: Amish Chadha
  change: First build plan at TRL 3, text only (withdrawn)
- version: "0.2"
  date: '2026-09-30'
  author: Amish Chadha
  change: Rewritten from the template with pictures by component and step; design made constructable (PPR-DDR-004)
- version: "0.3"
  date: '2026-09-30'
  author: Amish Chadha
  change: Open decisions moved to the design decisions register
- version: "0.4"
  date: '2026-10-01'
  author: Amish Chadha
  change: Budget treated as a value-engineering target
- version: "0.5"
  date: '2026-10-02'
  author: Amish Chadha
  change: Decisions of 2026-10-02 carried in; fixed inner shield behind a longer pump slot (section 3.10, steps 14 and 16, new pictures); handle operating space on the floor; first checks and safety stops for the ISO 13857 desk check
- version: "0.6"
  date: '2026-10-03'
  author: Amish Chadha
  change: 'Four guard fixes decided by Amish (2026-10-03): 6.35 mm mesh on the front strips, lower front panel, gate and roof; small-hole plates; top beam cover plates; crank bracket covers (sections 3.10 and 3.11, steps 14 and 15, new pictures); cost $1,169'
---

# PotPress prototype build plan

**Plan, not yet built.** How to build the first proof-of-concept prototype, component by component. Building and testing to it is TRL 4 work. Decisions still to be made are kept in the design decisions register ([docs/06-design-decisions.md](06-design-decisions.md)), not here.

## 1. What you are building

Figure 1. Every component, pulled apart and numbered in build order

*Figure 1. Every component pulled apart and numbered in build order.*

The prototype is a 20 t bottle-jack press that squeezes a clay charge between two cast aluminium molds to form a ceramic water filter pot, inside welded mesh guards with an interlocked front gate, plus a separate four-station rack for flow-testing finished pots. Figure 1 shows the 19 groups of parts in the order you make or fit them. The steel frame is a base beam and a top crossbeam, each two channels side by side, joined by two upright pairs with bolts; the jack pushes a moving platen up the uprights, and the platen carries rails on which a carriage slides the lower (female) mold in and out. The upper (male) mold hangs from a square stem that is pinned to the top crossbeam for pressing and wound up and down by a hand crank. The work is sawing, drilling and stick welding steel channel, plate and bar; 3D printing two casting patterns; having a local foundry sand-cast the two molds; hand finishing and lapping the molds; printing a gauge; and fitting bought parts (jack, springs, bolts, lead screw, mesh, buckets). The parts cost about $1,169 from the bill of materials, which is $109 over the $1,060 value-engineering target.

> **Safety:** PotPress is a 20 t hydraulic press. A crushing hazard exists wherever the platen, molds or stem move. Its build involves stick welding, grinding galvanised mesh (zinc fume), lifts of up to 40 kg to 1.5 m, and a foundry pour done by others. Never pump the jack with anyone's hands inside the guard, never pump with the load pin out or half in, and do not go past hand pressure before the safety stops in section 6 allow it. Nothing in this plan authorises a pressing test; that is TRL 4 work and on hold.

## 2. What changed to make it buildable

The concept showed what the press does; some of its parts could not be made or fitted as drawn. Each change keeps what the press does and is recorded in decision record PPR-DDR-004, accepted by Amish on 2026-09-30.

*Table 1. Changes from the concept.*

| Component | The concept had | The buildable design has | Why |
| --- | --- | --- | --- |
| Male mold | A closed hollow shell a foundry could not core | A plug open at the top; its inside forms its own sand core (Figure 15) | A one-piece flat-back pattern, no core box |
| Male mold flange | 25 mm thick; about 487 MPa at full load on the stop | 45 mm thick, 450 mm across; the stem's disc bears on the plug floor; 62 MPa (Figure 16) | Cast aluminium yields at about 90 MPa |
| Mold location | A 390 mm lip turned to 0.1 mm, needing a 420 mm lathe | Two 16 mm dowels and two steel bushes, drilled with the molds clamped together; stop faces lapped flat (Figure 14) | A pillar drill and a bench do it |
| Female mold | One casting with a thick base | A cast cup bedded and screwed on a 15 mm steel base plate (Figure 13) | The plate takes the rails and the retaining pins |
| Jack and pump slot | Pump socket in a return spring; handle path through an upright | Jack turned 25 degrees to the right front; slot moved onto the handle's line and widened to 30 mm (Figure 20) | The handle clears everything over its stroke |
| Pump slot guard | A slot with only a brush strip behind it | A slot 272 mm long with a fixed steel tunnel behind it round the handle's path to the jack body (Figure 20) | Only the handle can be reached through the slot; no finger is trapped at the ends of the stroke |
| Lead screw | Would have carried press force | Captive nut with 8 mm of free travel; press force goes through the pin (Figure 18) | The screw only lifts |
| Pin block | Hit the fixed screw when cranked up | A 28 mm hole down its middle | The screw passes as the stem rises 200 mm |
| Uprights in the beams | 100 mm uprights in a 100 mm gap | 104 mm gap with 2 mm shims (Figure 7) | Rolled channel varies |
| Joint bolts | M20, too big for the channel flange, clamping across a hollow | Four M16 grade 10.9 per joint with spacer tubes inside (Figure 7) | Correct edge distance; flanges do not fold |
| Stem guidance | 7 mm of play front to back | Plastic strips on the top beam webs, 1 mm each side (Figure 9) | The dowels always find their bushes |
| Carriage | Tilt bosses with nothing to pivot on; no mold retention; handle in the wrong place | Hooks on tipping pins, retaining pins, two lift handles (Figure 12) | The mold can be tipped out safely |
| Rail extension | Folded into the gate when the platen went down | Hinge line 30 mm further back | Clears the gate and lower panel |
| Feet | Channels lying on their flange tips; no fixings | Channels web up with welded studs and anchor tubes; four floor anchors (Figure 4) | A flat face to bolt through |
| Interlock | Outline shapes | A lock disc, lock rod, gate slider and pin slider round the jack's release screw (Figures 23 and 24) | Purely mechanical, detailed enough to make |
| QC rack | Buckets overlapping the hanging pots | Pot shelf raised to 720 mm; 35 mm between pot and bucket (Figure 25) | Room for the water to drip |
| Assembly order | Not worked out | The order of section 4, set by what fits past what | The stem and molds only go in this way |

## 3. Making the components

Make and check each component before the assembly step that needs it. Sizes are in millimetres. "Left" and "right" are as seen standing in front of the press, at the gate; "front" is the gate side. Workshop tolerance is 0.5 mm unless a step says otherwise. Weld with 3.2 mm E6013 electrodes; unless stated, fillets are 6 mm. Load-path welds (doublers, jack pad, sleeves, pin block, stem to disc) should be made by a competent welder. Mark every part with its name in paint marker as you make it.

### 3.1 Feet (make 2)

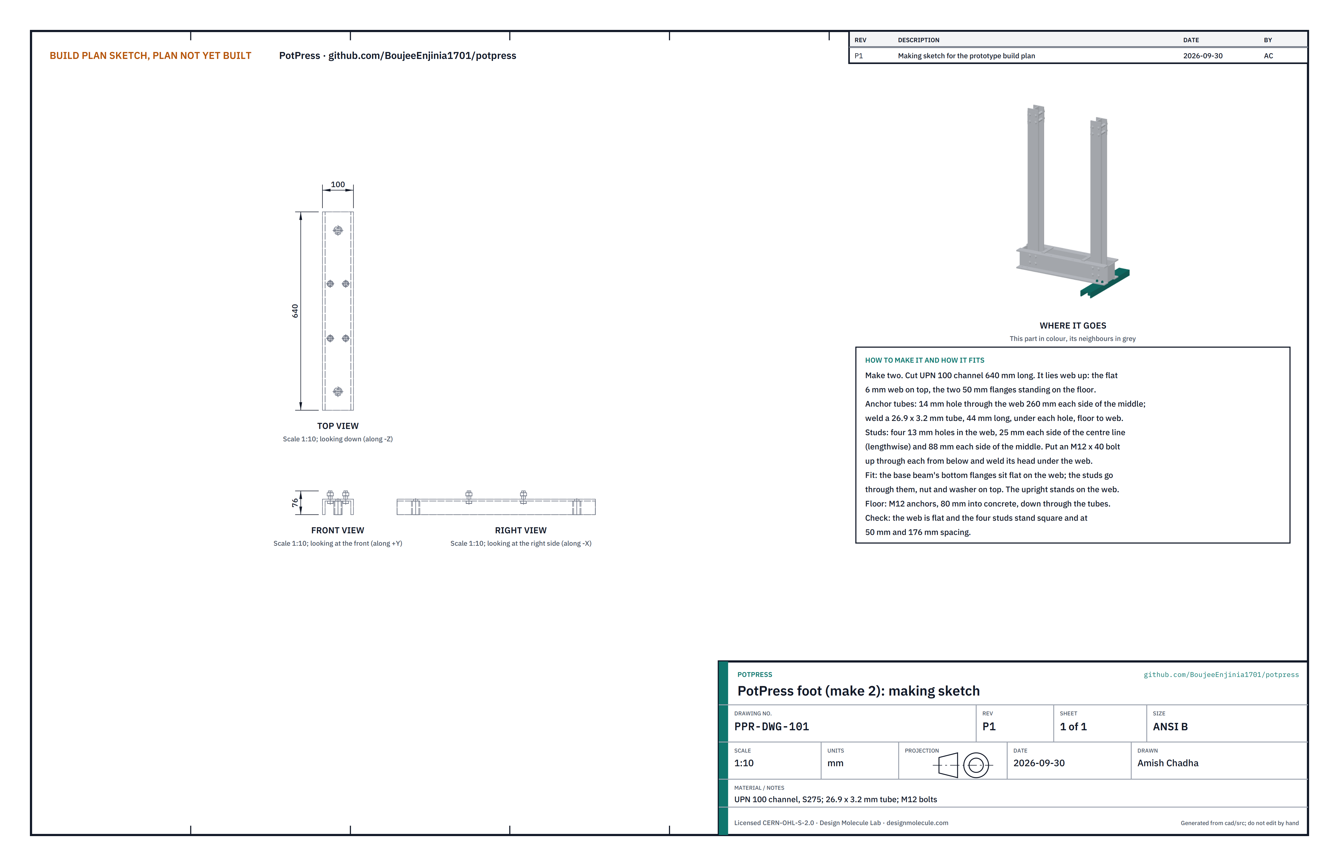
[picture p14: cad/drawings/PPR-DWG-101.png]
Figure 2. Making sketch of the foot


*Figure 2. Foot making sketch (PPR-DWG-101).*

**What it is and what it is made from.** The two feet carry the whole press and fix it to the floor. UPN 100 steel channel, S275, 640 mm long each; 26.9 x 3.2 mm steel tube; M12 x 40 bolts.

**How to make it.**

1. Saw two 640 mm lengths of channel with square ends; deburr.
2. Lay each web up (the flat 6 mm web on top, the two 50 mm flanges down).
3. Anchor holes: a 14 mm hole through the web on the centre line, 260 mm each side of the middle.
4. Weld a 26.9 x 3.2 mm tube, 44 mm long, under each anchor hole, from the floor up to the web, so the anchor has a sleeve.
5. Stud holes: four 13 mm holes, 25 mm each side of the centre line and 88 mm each side of the middle (a rectangle 50 x 176).
6. Push an M12 x 40 bolt up through each stud hole from below and weld its head to the underside of the web, square.

**How it fits the parts next to it.** The base beam's bottom flanges sit flat on the web; the studs go up through them and take a washer and nut (Figure 4). The upright pair stands on the web between the beam's channels. The anchors go down the tubes into the floor.

**Check before moving on.** The web is flat within 1 mm; the four studs stand square to it at 50 and 176 mm centres.

### 3.2 Base beam and jack plate

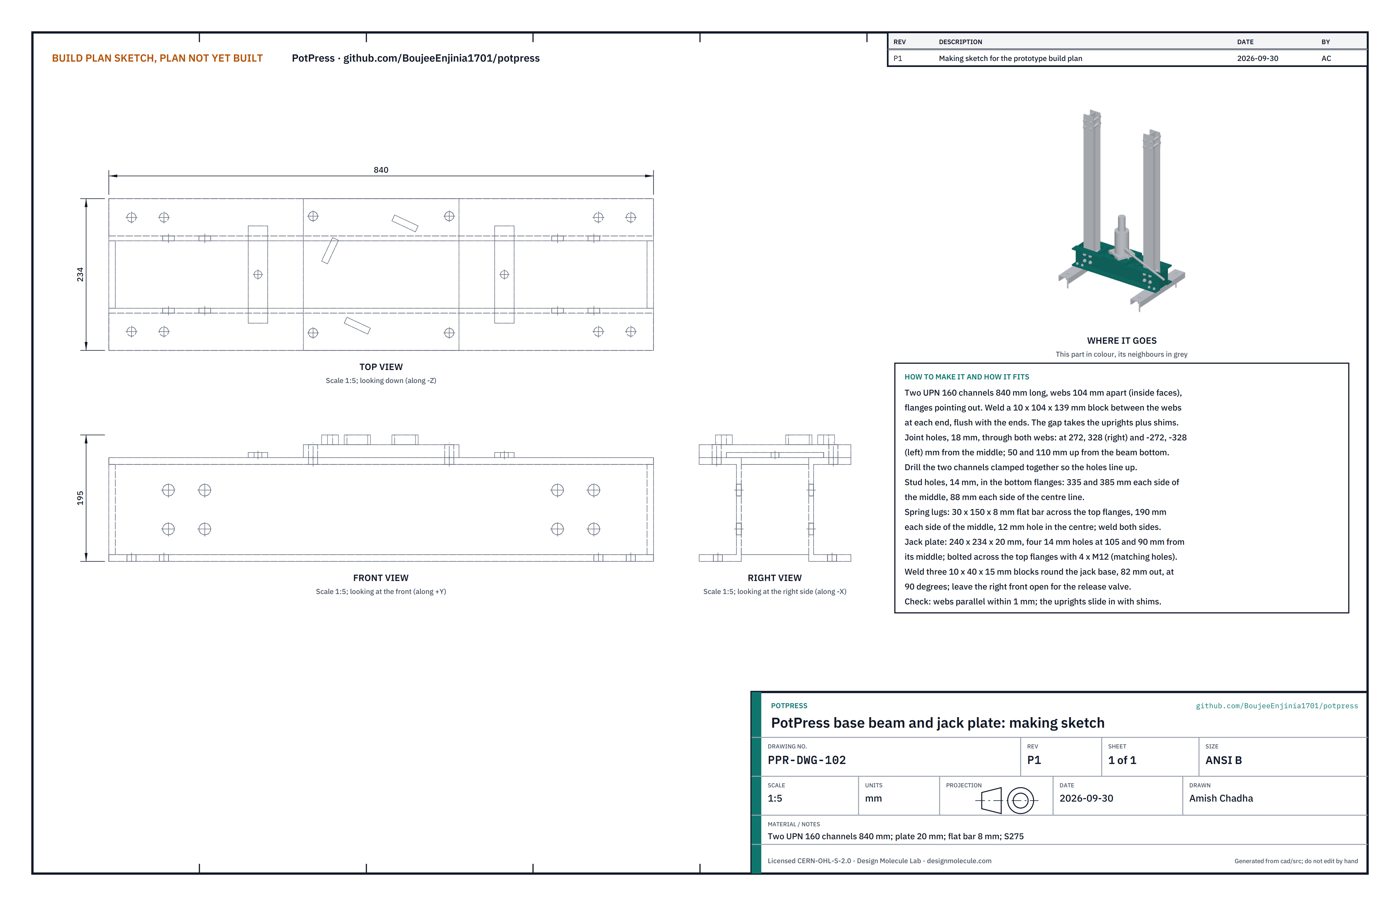
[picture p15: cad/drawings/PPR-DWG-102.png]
Figure 3. Making sketch of the base beam and jack plate


*Figure 3. Base beam and jack plate making sketch (PPR-DWG-102).*

**What it is and what it is made from.** The lower beam that the jack pushes down on and the uprights bolt into, with the bolted plate the jack stands on. Two UPN 160 channels, S275, 840 mm long; 10 mm plate for the end blocks; 20 mm plate for the jack plate; 8 mm flat bar for the spring lugs; 10 x 40 bar for the locating blocks.

**How to make it.**

1. Saw both channels to 840 mm. Lay them flanges out, webs 104 mm apart (inside faces), on a flat table.
2. Cut two blocks 10 x 104 x 139 mm and weld one between the webs at each end, flush with the ends. The gap now stays 104 mm.
3. Joint holes, 18 mm, through both webs: 272 and 328 mm each side of the middle, at 50 and 110 mm up from the bottom of the beam. Drill each web from outside with the beam on its side, or both at once with a magnetic drill.
4. Stud holes, 14 mm, in the bottom flanges: 335 and 385 mm each side of the middle, 88 mm each side of the centre line. Check them against the studs on the feet.
5. Spring lugs: two 30 x 150 x 8 mm bars across the top flanges, centred 190 mm each side of the middle, a 12 mm hole in the centre of each. Weld both ends.
6. Jack plate holes, 14 mm, in the top flanges: 105 mm each side of the middle, 90 mm each side of the centre line.
7. Jack plate: cut 240 x 234 x 20 mm; drill four 14 mm holes to match step 6. Stand the jack you have bought on it, centred and turned so its pump socket and release valve point to the right front, 25 degrees in front of the right-hand direction. Weld three 10 x 40 x 15 mm blocks round its base, about 2 mm off it, at 90 degrees to each other, leaving the right front open.

**How it fits the parts next to it.**

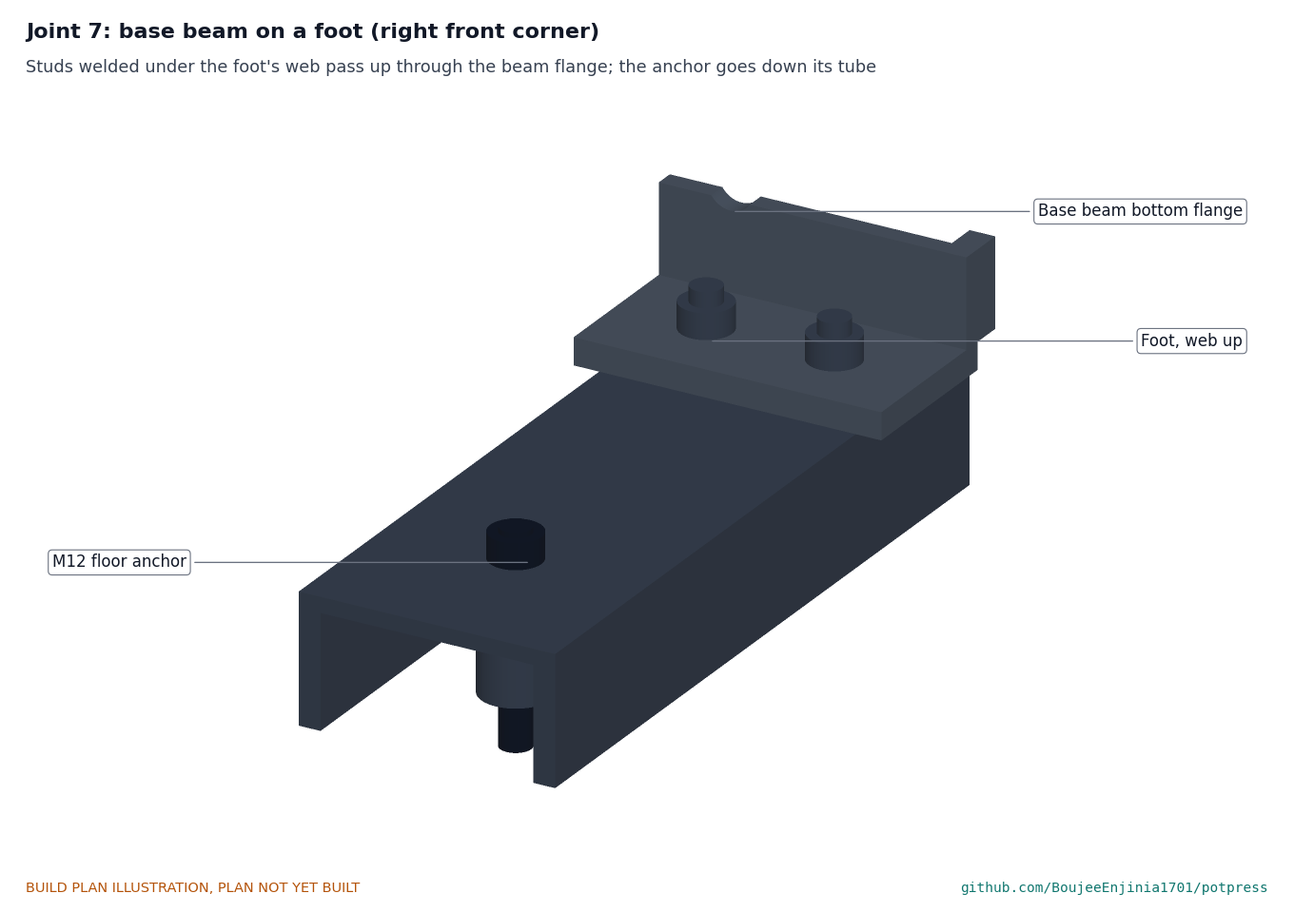
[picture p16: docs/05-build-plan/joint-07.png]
Figure 4. Joint 7: base beam on a foot


*Figure 4. Joint 7. The beam's bottom flange sits on the foot's web; the studs pass up through it.*

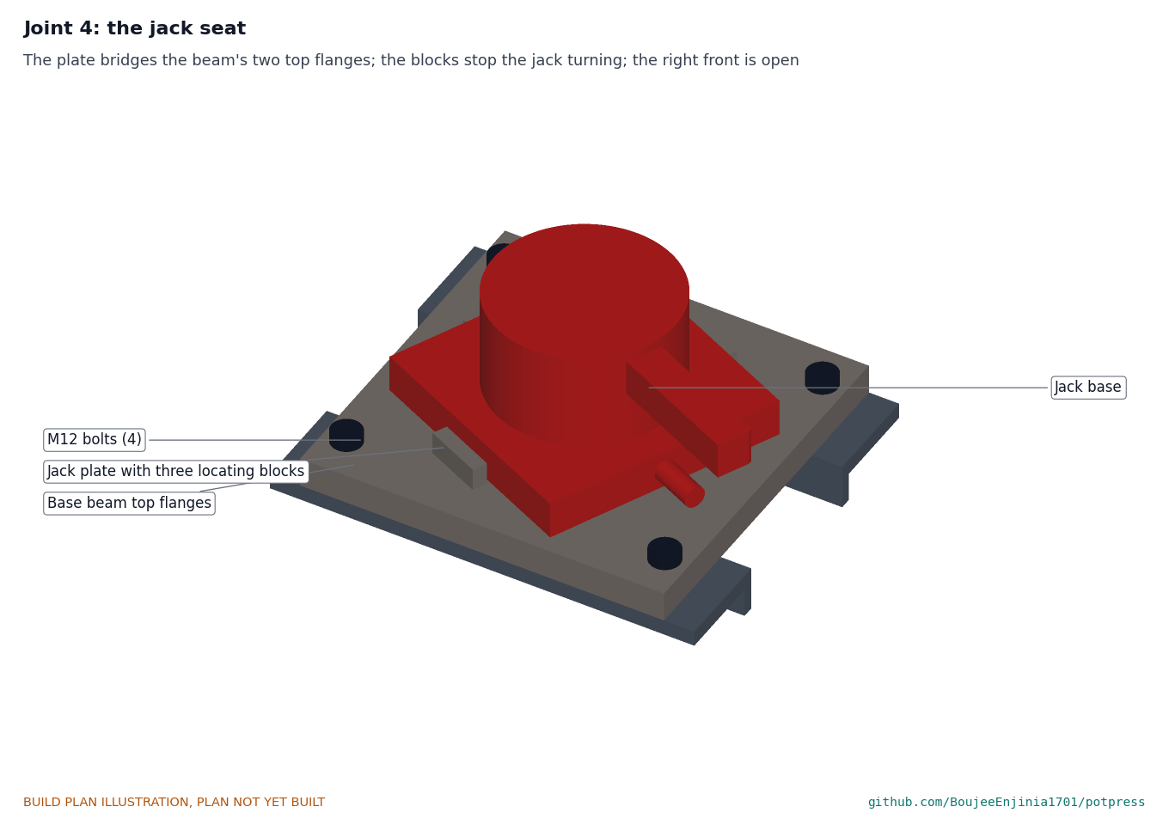
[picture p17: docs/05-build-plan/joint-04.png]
Figure 5. Joint 4: the jack seat


*Figure 5. Joint 4. The jack plate bridges the two top flanges and is held by four M12 bolts with nuts under the flanges; the blocks stop the jack turning.*

**Check before moving on.** Webs parallel within 1 mm end to end; an offcut of upright pair with a 2 mm shim each side slides into the gap by hand.

### 3.3 Upright pairs (make 2)

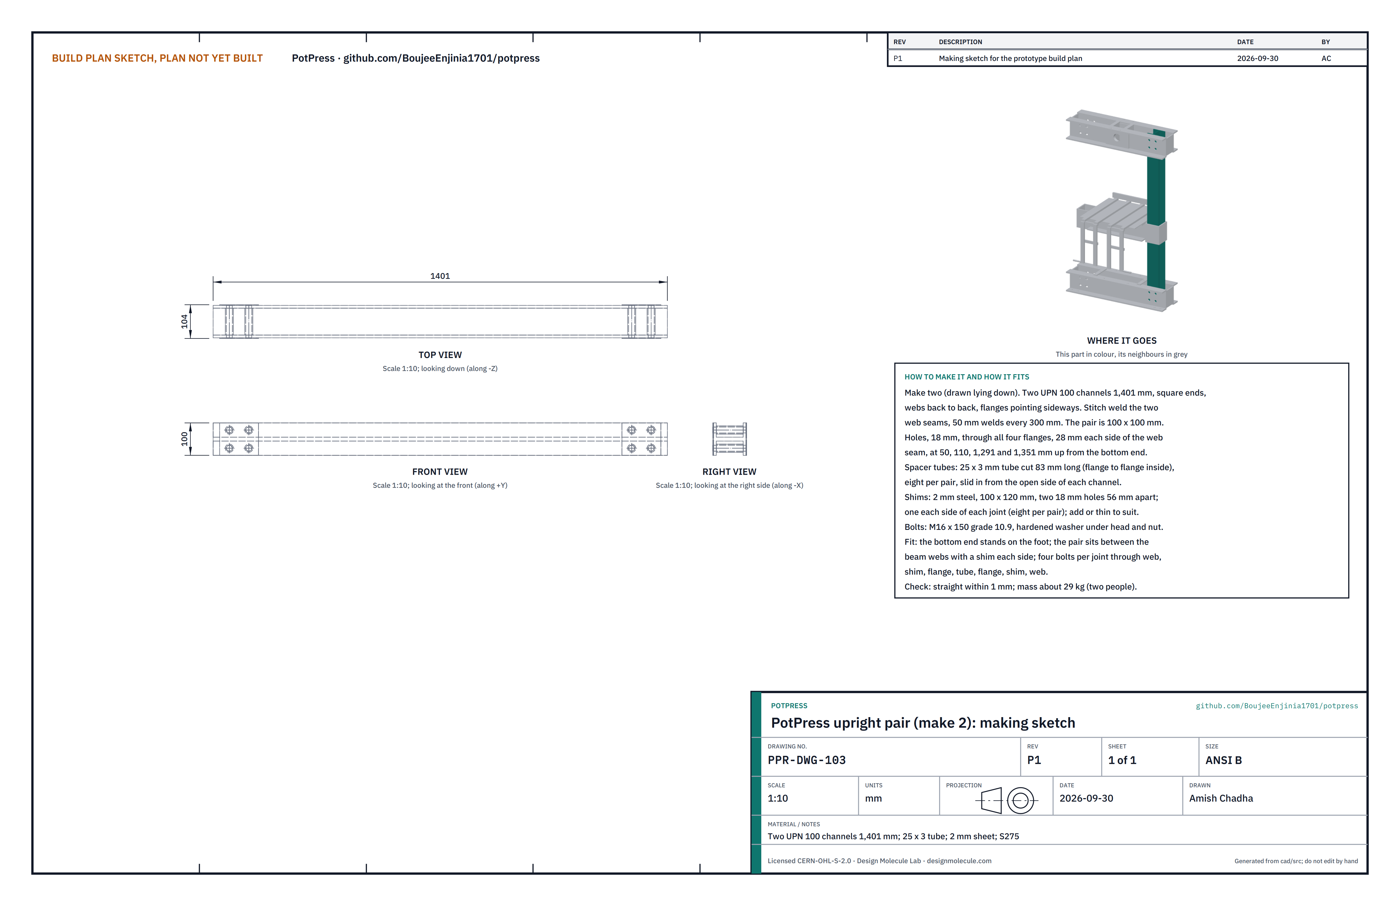
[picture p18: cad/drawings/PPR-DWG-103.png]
Figure 6. Making sketch of the upright pair


*Figure 6. Upright pair making sketch (PPR-DWG-103), drawn lying down.*

**What it is and what it is made from.** The two posts that carry the press force from the top crossbeam down to the base beam, and guide the platen. Each is two UPN 100 channels back to back. S275; 25 x 3 mm tube; 2 mm steel sheet; M16 x 150 grade 10.9 bolts with hardened washers and nuts.

**How to make it.**

1. Saw four channels to 1,401 mm with square ends; the ends set the top beam height.
2. Clamp two channels web to web, flanges pointing sideways, ends flush. Stitch weld both seams: 50 mm welds every 300 mm. The pair is 100 x 100 mm.
3. Holes, 18 mm, through all four flanges, 28 mm each side of the web seam, at 50, 110, 1,291 and 1,351 mm up from the bottom end. Drill the two flanges of each channel as a pair so they line up.
4. Cut eight spacer tubes 83 mm long from 25 x 3 mm tube per pair (the distance between the flanges inside the channel).
5. Cut eight shims per pair from 2 mm sheet, 100 x 120 mm, each with two 18 mm holes 56 mm apart, matching the flange holes.

**How it fits the parts next to it.**

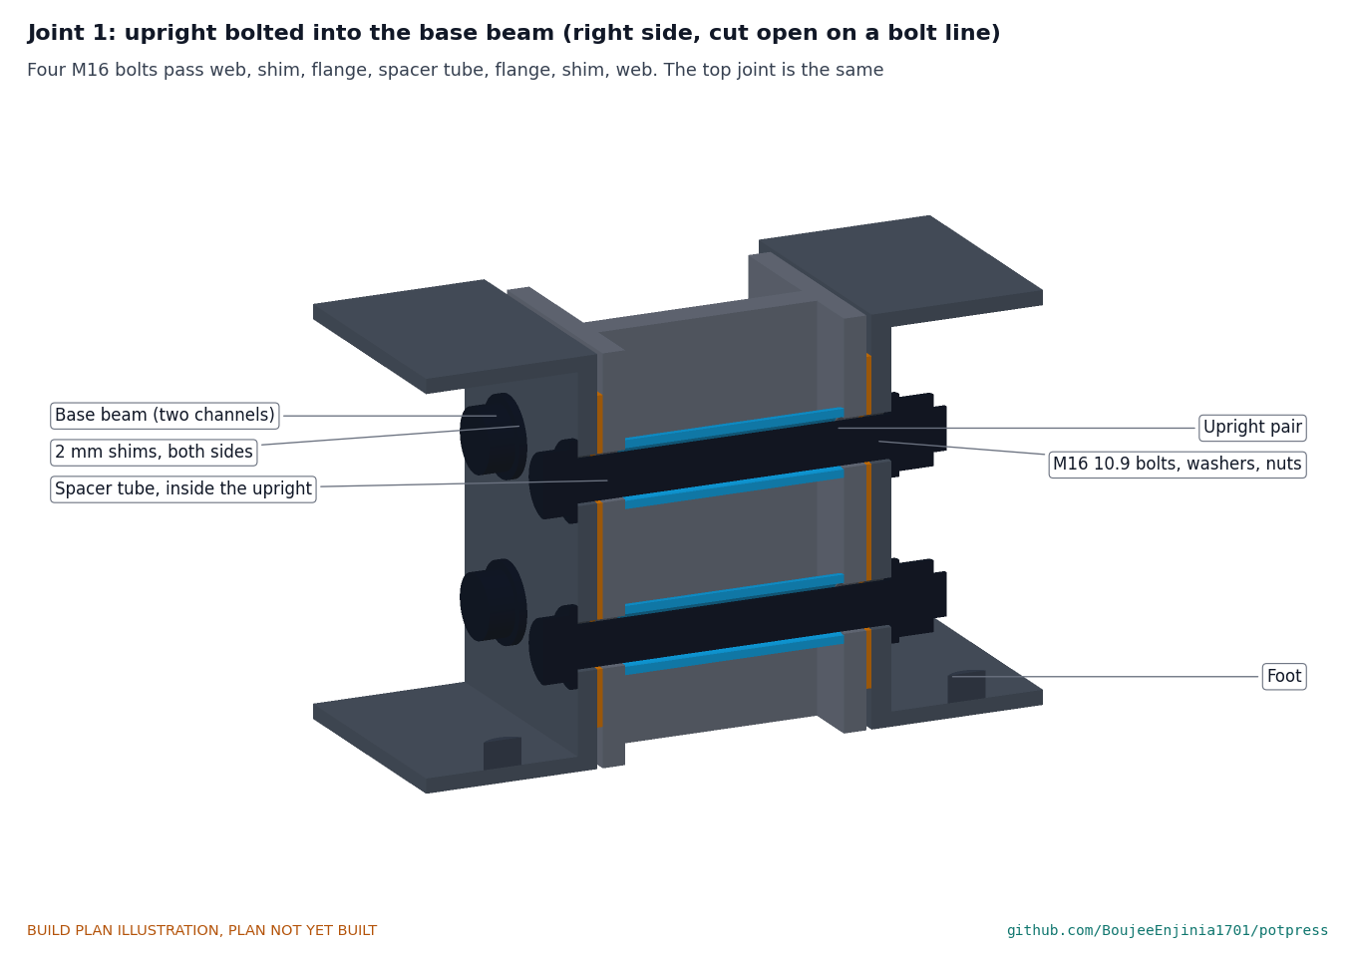
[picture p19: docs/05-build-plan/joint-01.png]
Figure 7. Joint 1: upright bolted into the base beam


*Figure 7. Joint 1, cut open on one bolt line. Each bolt passes beam web, shim, upright flange, spacer tube, upright flange, shim, beam web.*

The bottom end stands on the foot's web. The pair sits between the beam webs with a shim each side; the spacer tubes slide into the open side of each channel and line up with the holes, so tightening the bolts cannot fold the flanges. The top joint into the top crossbeam is the same. If a joint is loose, add shim; if tight, thin it.

**Check before moving on.** Straight within 1 mm over its length; about 29 kg, so two people carry it.

### 3.4 Top crossbeam with doublers and guides

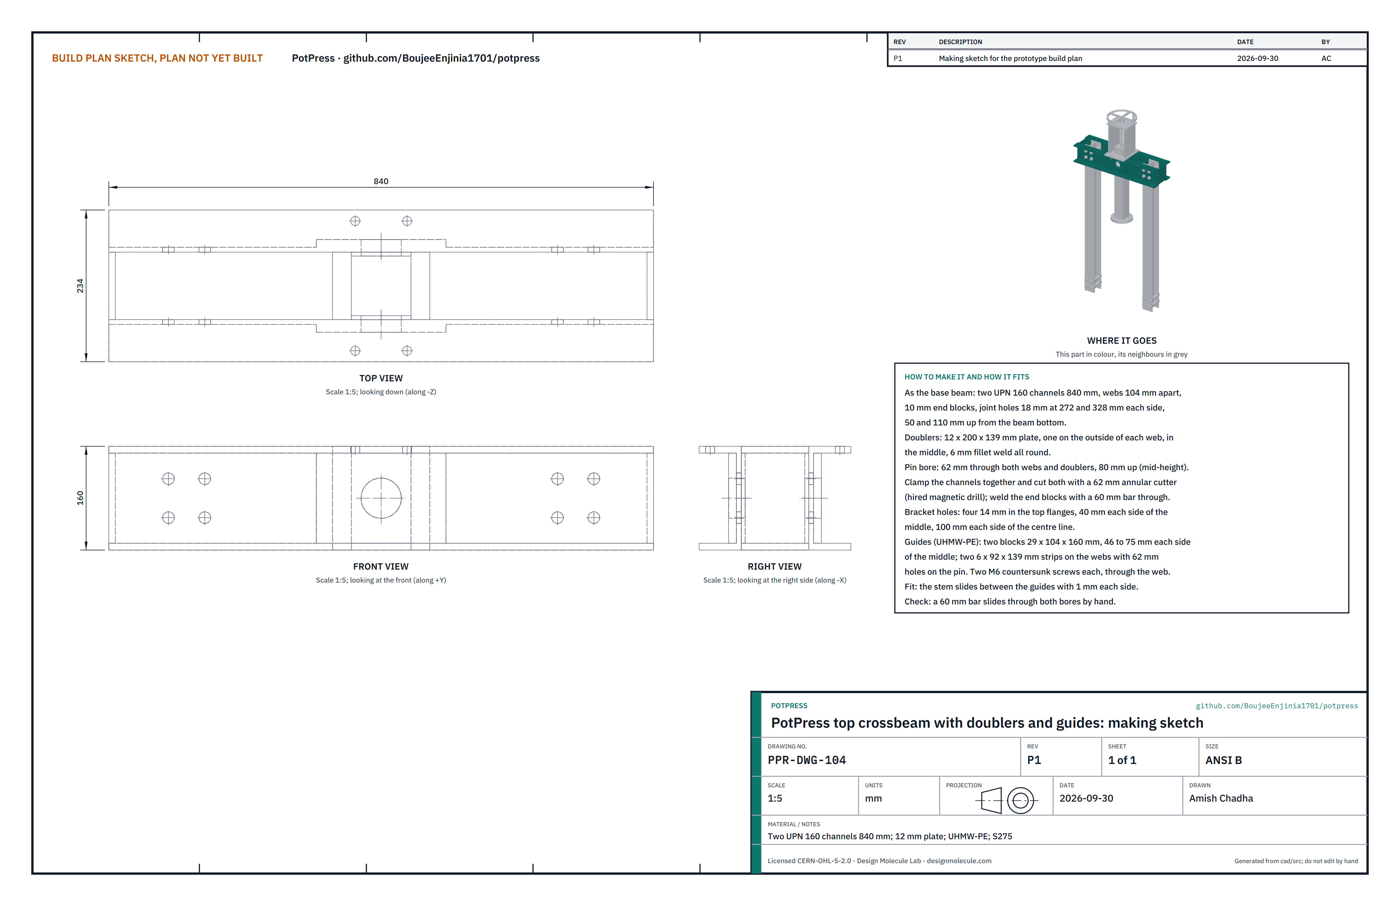
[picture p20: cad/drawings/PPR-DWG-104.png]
Figure 8. Making sketch of the top crossbeam


*Figure 8. Top crossbeam making sketch (PPR-DWG-104).*

**What it is and what it is made from.** The upper beam that the load pin hangs the male mold from; it takes the full press force. Two UPN 160 channels 840 mm, S275; 12 mm plate doublers; 10 mm end blocks; UHMW-PE plastic for the stem guides.

**How to make it.**

1. Make the two channels, end blocks and joint holes exactly as the base beam (section 3.2, steps 1 to 3), but do not weld the end blocks yet.
2. Doublers: two plates 12 x 200 x 139 mm. Weld one to the outside of each web, in the middle, 6 mm fillet all round. This is a load-path weld.
3. Pin bore: clamp the two channels web to web and cut a 62 mm hole through both webs and both doublers, in the middle, 80 mm up (half height). Use a 62 mm annular cutter in a hired magnetic drill.
4. Set the channels 104 mm apart again with a 60 mm steel bar through both bores, and weld the end blocks in. The bar keeps the bores in line.
5. Bracket holes: four 14 mm holes in the top flanges, 40 mm each side of the middle, 100 mm each side of the centre line.
6. Guides: two UHMW-PE blocks 29 x 104 x 160 mm, placed between the webs 46 to 75 mm each side of the middle; two UHMW-PE strips 6 x 92 x 139 mm on the inside faces of the webs between the blocks, each with a 62 mm hole on the pin bore. Fix each with two M6 countersunk screws through the web.

**How it fits the parts next to it.**

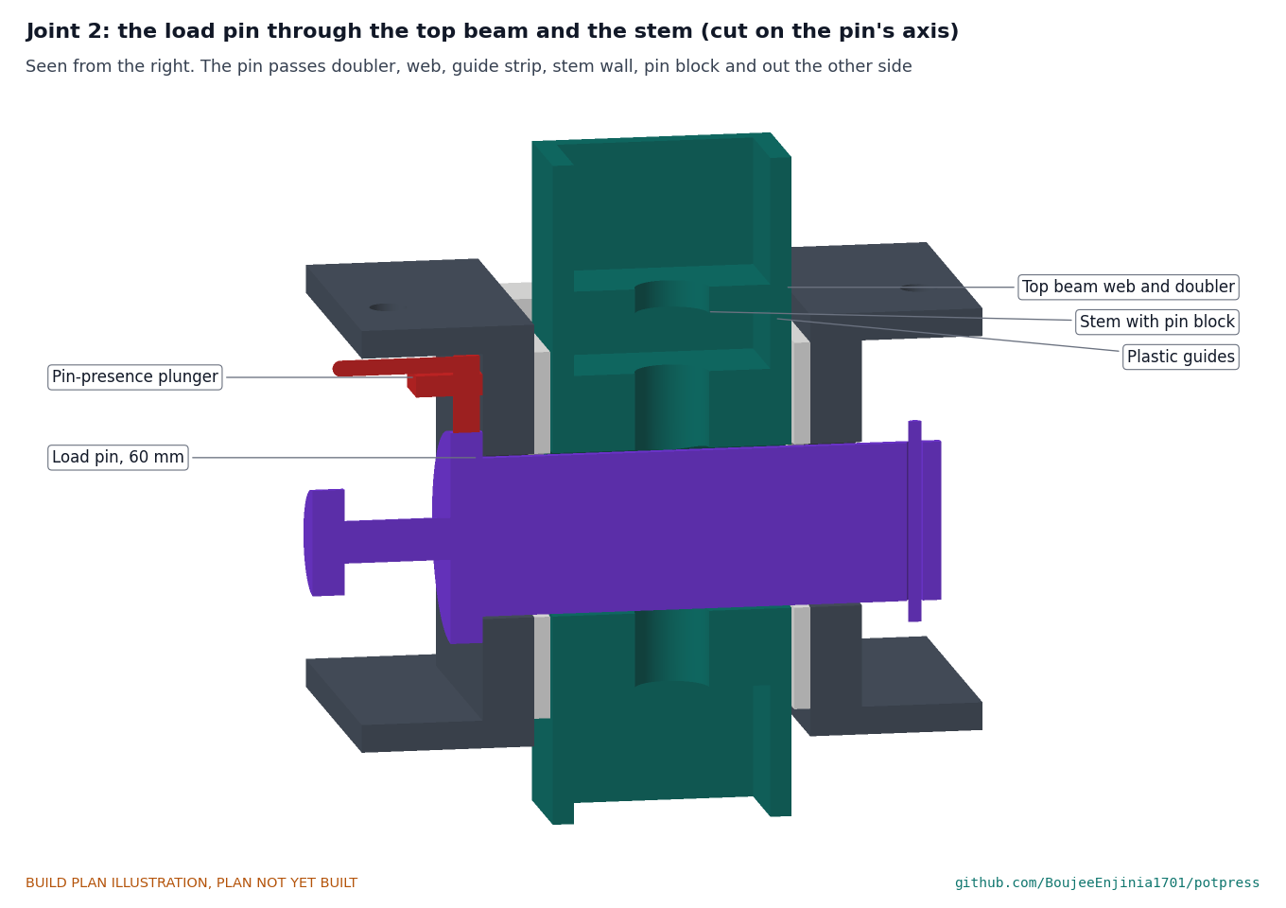
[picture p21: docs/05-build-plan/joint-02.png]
Figure 9. Joint 2: the load pin through the top beam and the stem


*Figure 9. Joint 2, cut on the pin's axis. The pin passes the doubler, web, guide strip, stem wall and pin block, then the same on the far side.*

The uprights bolt in as Figure 7. The stem slides between the four guides with 1 mm each side. The crank bracket bolts on top.

**Check before moving on.** A 60 mm bar slides through both bores by hand; the two bores are in line within 0.5 mm.

### 3.5 Moving platen, rails and hinged extension

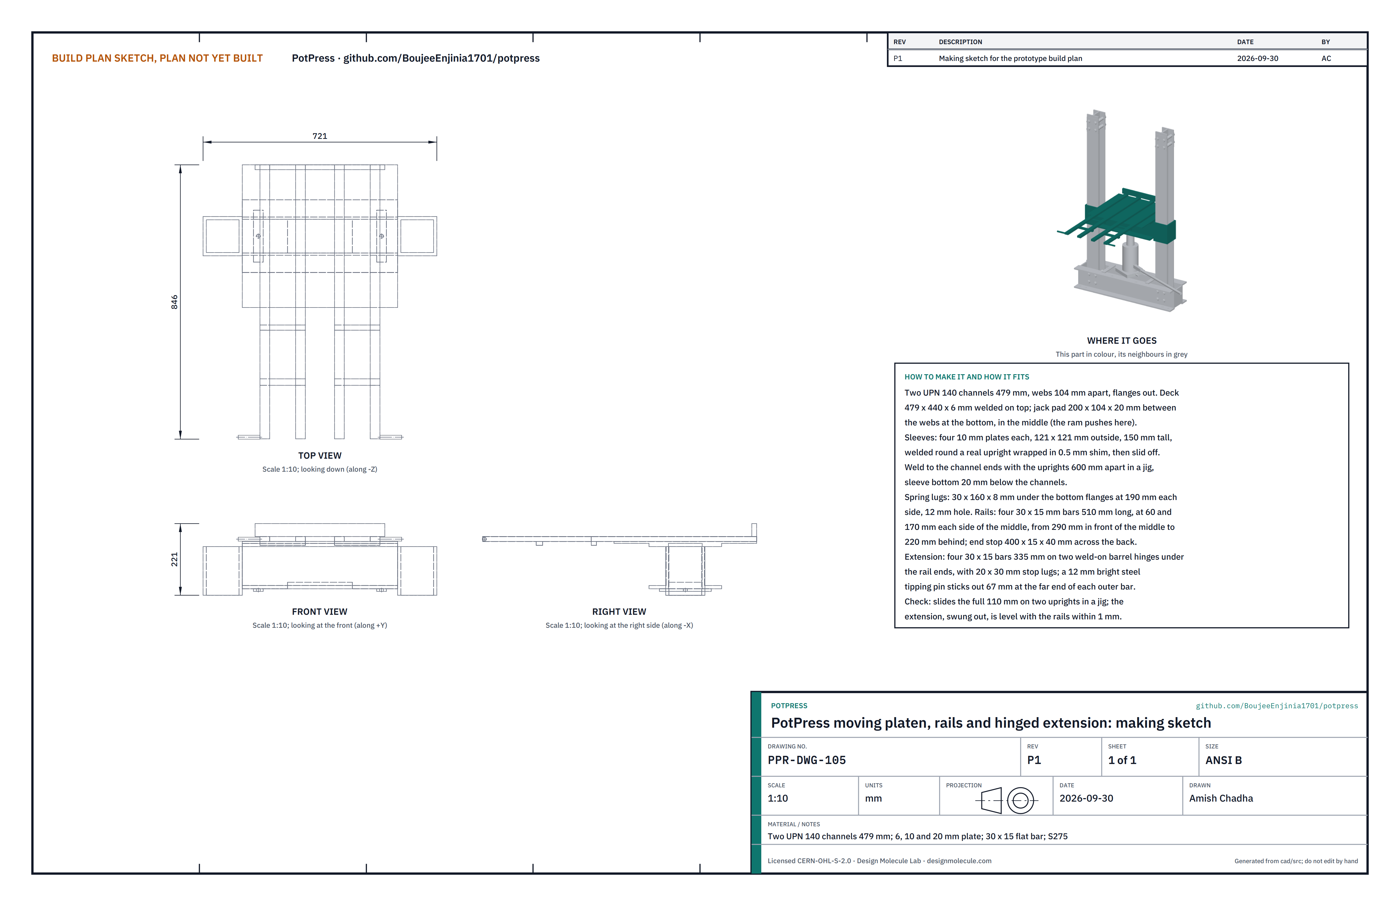
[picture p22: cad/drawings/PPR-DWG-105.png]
Figure 10. Making sketch of the platen, rails and extension


*Figure 10. Platen, rails and hinged extension making sketch (PPR-DWG-105), extension shown swung out.*

**What it is and what it is made from.** The platen is pushed up by the jack and slides on the uprights; the rails on it carry the mold carriage, and the extension swings out in front to take the carriage for loading and demolding. Two UPN 140 channels 479 mm; 6, 8, 10 and 20 mm plate; 30 x 15 mm flat bar; two weld-on barrel hinges; 12 mm bright steel bar (EN8 or 1045). S275 unless stated. About 40 kg, the heaviest part.

**How to make it.**

1. Saw the channels to 479 mm; set them flanges out, webs 104 mm apart.
2. Jack pad: 200 x 104 x 20 mm, welded between the webs at the bottom, in the middle. The ram pushes here.
3. Deck: 479 x 440 x 6 mm, welded on the top flanges.
4. Sleeves: for each upright, wrap the real upright pair in 0.5 mm shim, clamp four 10 mm plates round it to make a square tube 121 x 121 mm outside and 150 mm tall, tack, slide it off, remove the shim, weld the corners. This gives about 1 mm clearance on the real, not nominal, upright.
5. Stand both uprights 600 mm apart (centres) in a jig, slide the sleeves on, and weld them to the channel ends with each sleeve's bottom 20 mm below the channels.
6. Spring lugs: 30 x 160 x 8 mm under the bottom flanges, 190 mm each side of the middle, 12 mm hole in the centre.
7. Rails: four 30 x 15 mm bars 510 mm long, flat on the deck, centred 60 and 170 mm each side of the middle, running from 290 mm in front of the middle to 220 mm behind it (they overhang the deck 70 mm at the front). Weld both sides. Weld a 400 x 15 x 40 mm end stop across them at the back.
8. Hinge bars: a 16 x 12 mm bar under each pair of rails at the front ends.
9. Extension: four 30 x 15 mm bars 335 mm long, joined in pairs by a 20 x 12 mm cross tie 150 mm from the hinge end. Weld the barrel hinges between the hinge bars and the extension so it swings down to hang in front of the platen, and weld 20 x 30 mm stop lugs so that, swung out, it stops level with the rails. The stop lugs carry up to about 11 kN each when a mold is tipped: weld them all round.
10. Tipping pins: weld a 12 mm bright steel pin across the far end of each outer extension bar, sticking out 67 mm to the side.
11. Grease the rail tops.

**How it fits the parts next to it.** The sleeves slide on the uprights; the jack pad sits on the ram; the springs hook into the lugs; the carriage slides on the rails between its side lips.

**Check before moving on.** On two uprights in the jig the platen slides the full 110 mm by hand without binding; the extension, swung out, is level with the rails within 1 mm and folds down freely.

### 3.6 Mold carriage

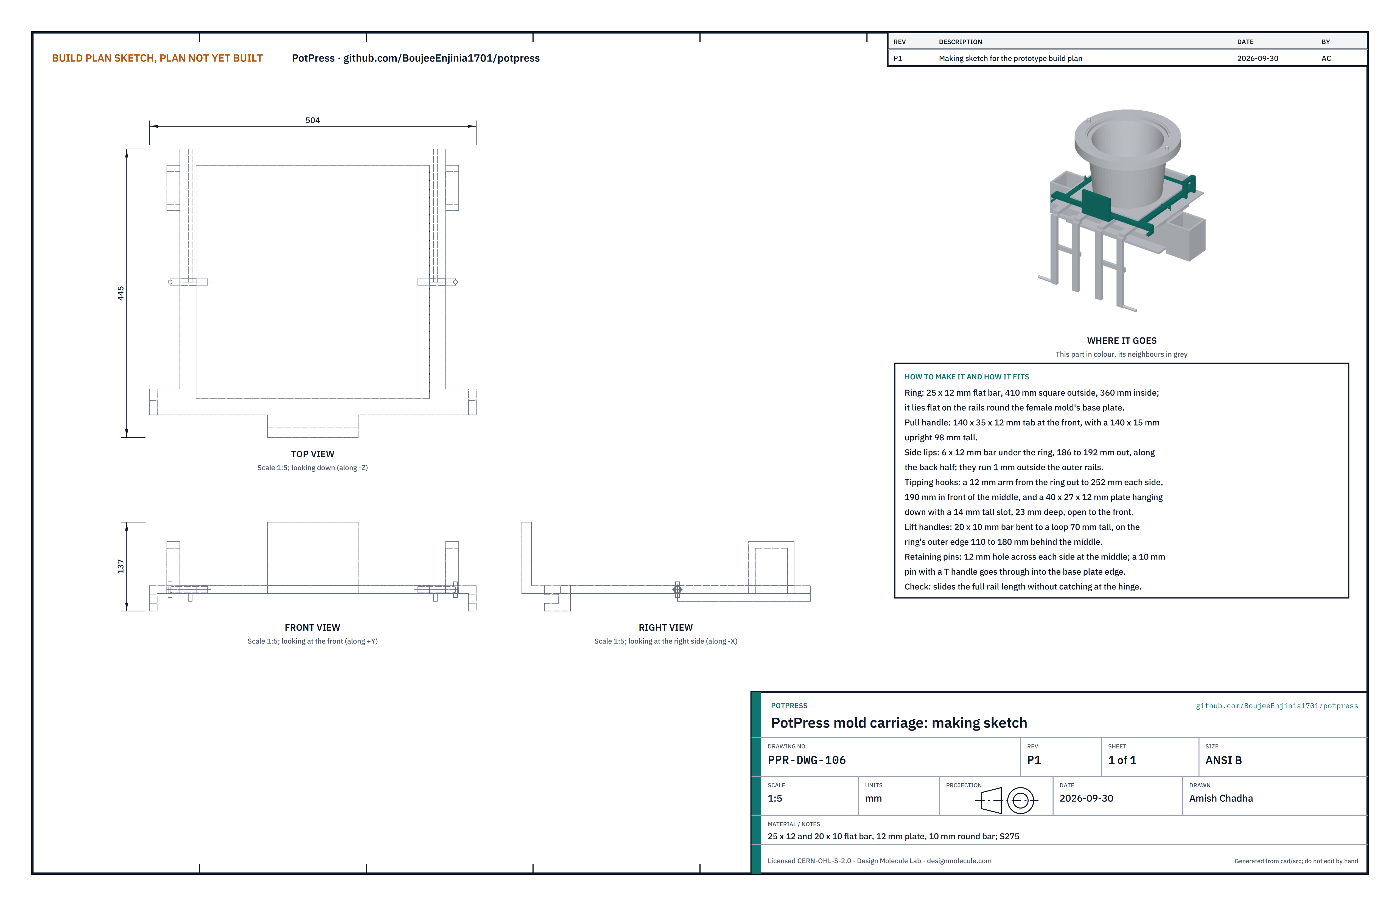
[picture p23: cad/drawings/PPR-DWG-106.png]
Figure 11. Making sketch of the mold carriage


*Figure 11. Mold carriage making sketch (PPR-DWG-106).*

**What it is and what it is made from.** A square steel ring that slides the female mold in and out on the rails and tips it out for demolding. 25 x 12 and 20 x 10 mm flat bar, 12 mm plate, 10 mm round bar; S275.

**How to make it.**

1. Ring: 25 x 12 mm bar, 410 mm square outside and 360 mm inside, welded flat.
2. Pull handle: a 140 x 35 x 12 mm tab at the front with a 140 x 15 mm upright 98 mm tall.
3. Side lips: 6 x 12 mm bar under the ring, 186 to 192 mm out from the middle, along the back half; they run just outside the outer rails and keep the carriage straight.
4. Tipping hooks: a 12 mm arm from each side of the ring out to 252 mm from the middle, 190 mm in front of the middle, and a 40 x 27 x 12 mm plate hanging from it with a slot 14 mm tall and 23 mm deep, open to the front.
5. Lift handles: 20 x 10 mm bar bent to a loop 70 mm tall, welded to the ring's outer edge 110 to 180 mm behind the middle, one each side.
6. Retaining pins: a 12 mm hole across each side of the ring at the middle; two 10 mm pins with T handles.

**How it fits the parts next to it.**

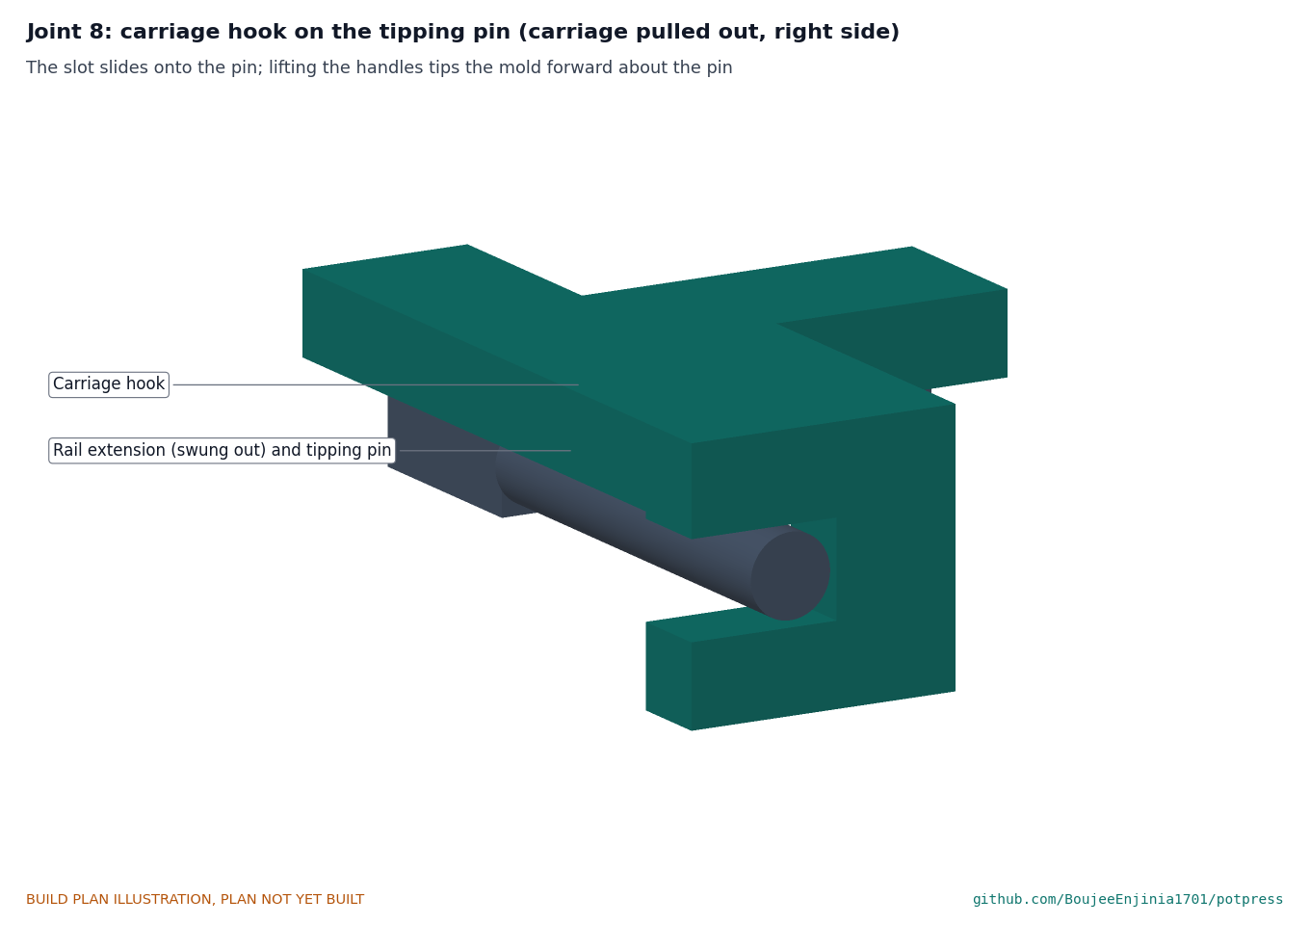
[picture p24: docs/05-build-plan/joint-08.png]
Figure 12. Joint 8: carriage hook on the tipping pin


*Figure 12. Joint 8, with the carriage pulled out. The slot slides onto the pin; lifting the handles tips the mold forward about the pin.*

The ring lies on the rails round the female mold's base plate; the retaining pins go through it into holes in the plate's edges. Pulled fully out, 430 mm, the hooks meet the tipping pins; lifting both handles (about 14 kg each to start) turns the mold over forward onto a board.

**Check before moving on.** Slides the full length of the rails and extension without catching at the hinge.

### 3.7 Casting patterns and the female mold

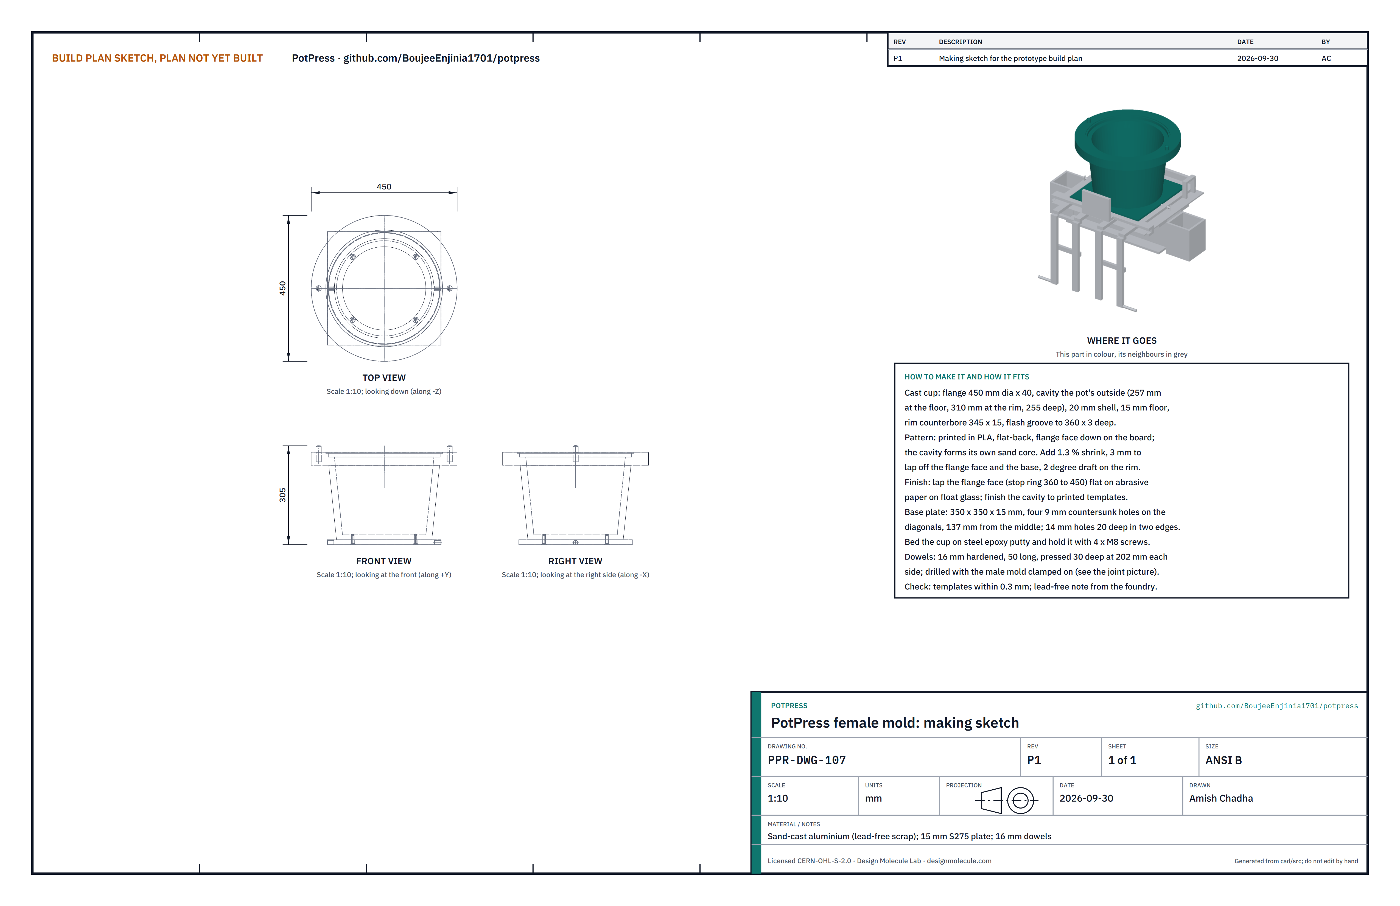
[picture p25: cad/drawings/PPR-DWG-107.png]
Figure 13. Making sketch of the female mold


*Figure 13. Female mold making sketch (PPR-DWG-107).*

**What it is and what it is made from.** The lower mold, which forms the outside of the pot. A sand-cast aluminium cup made by a local foundry from a 3D-printed pattern, from lead-free scrap (cast wheels or pistons, never free-machining bar), bedded and screwed on a steel base plate. About 36.5 kg with its plate.

**How to make it.**

1. **Pattern.** Print the cup in PLA, scaled up 1.3 % for shrinkage, with 3 mm extra on the flange face (for lapping) and 2 degrees of draft on the flange rim. It is 456 mm across and 274 mm tall, so print it as four quarters in two layers (8 pieces) on a 250 mm printer. Glue with epoxy, fill the seams, sand to 240 grit, seal and wax.
2. **Casting.** The pattern is flat-backed: it sits flange face down on the moulding board, and the cavity stands up as a sand core of its own, so no core box is needed. Ask the foundry to record the scrap it melts.
3. **Stop face.** Lap the flange face (the ring from 360 to 450 mm across, outside the flash groove) flat: glue 80, then 120 grit wet-and-dry paper to a sheet of 6 mm float glass at least 500 mm square, lay the cup face down on it and rub in figure-eights until marking blue shows even contact all round.
4. **Cavity.** Finish the cavity to printed contour templates within 0.3 mm (radius 128.5 at the floor, 155.1 at the rim, 255 deep), with a die grinder, files and abrasive paper. Rim counterbore 345 mm across and 15 deep; flash groove to 360 mm across, 3 deep.
5. **Base plate.** Cut 350 x 350 x 15 mm steel plate. Drill four 9 mm holes on the diagonals, 137 mm from the middle, countersunk from below for M8. Drill a 14 mm hole 20 deep into the middle of the left and right edges for the retaining pins.
6. **Bedding.** Drill and tap the cup's underside M8, 16 deep, through the plate's holes. Spread steel-filled epoxy putty on the plate, press the cup down on it, fit the four screws, wipe off the excess and let it cure.
7. **Dowels.** Drilled with the male mold (section 3.8, step 5).

**How it fits the parts next to it.**

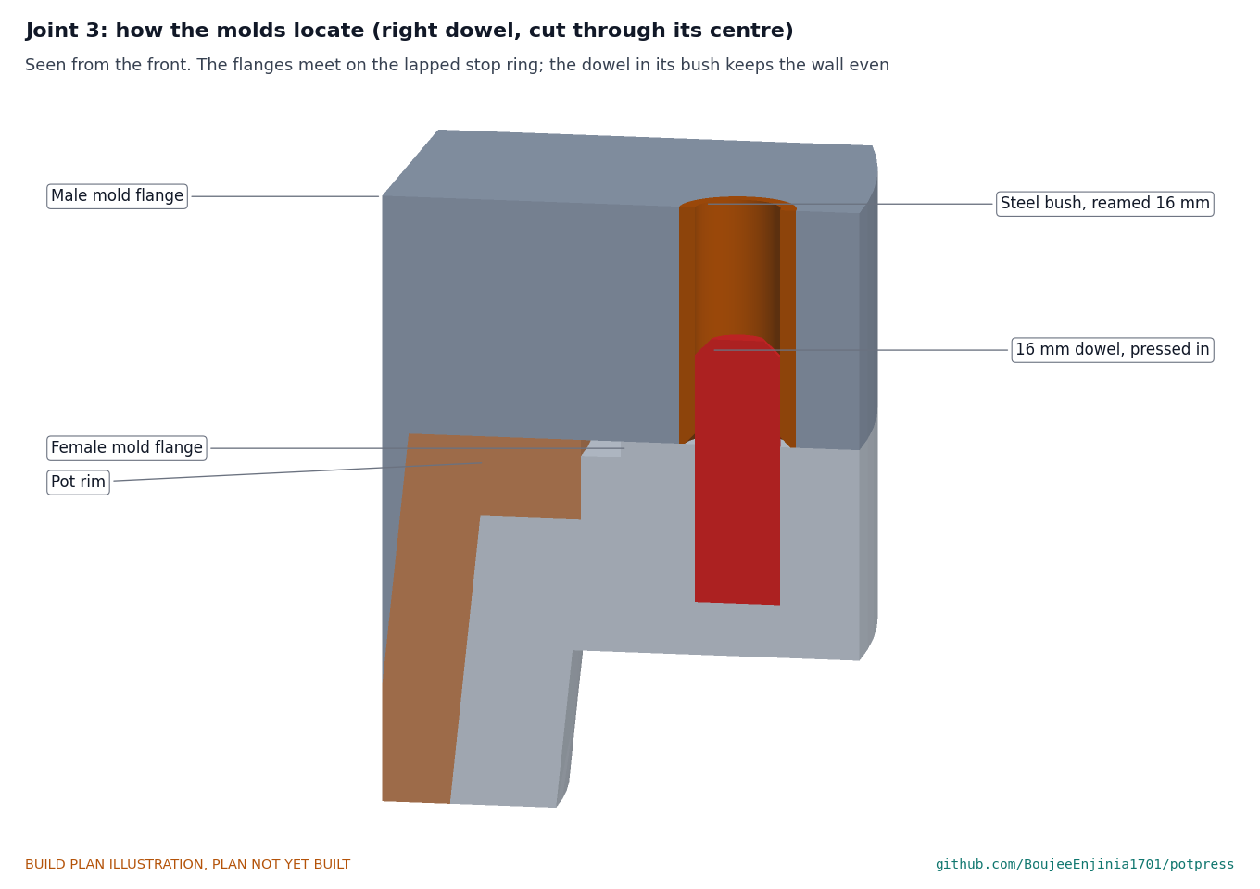
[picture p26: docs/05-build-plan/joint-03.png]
Figure 14. Joint 3: how the molds locate


*Figure 14. Joint 3, cut through the right dowel. The flanges meet on the lapped stop ring; the dowel in its bush keeps the wall even.*

The base plate sits on the rails inside the carriage ring. The male mold closes onto the stop ring; the pot's rim fills the counterbore.

**Check before moving on.** Templates touch the cavity within 0.3 mm at eight places round each of four heights; no porosity on the cavity or stop face; the foundry's lead-free note on file. **Hold point:** measure before assembly.

### 3.8 Male mold

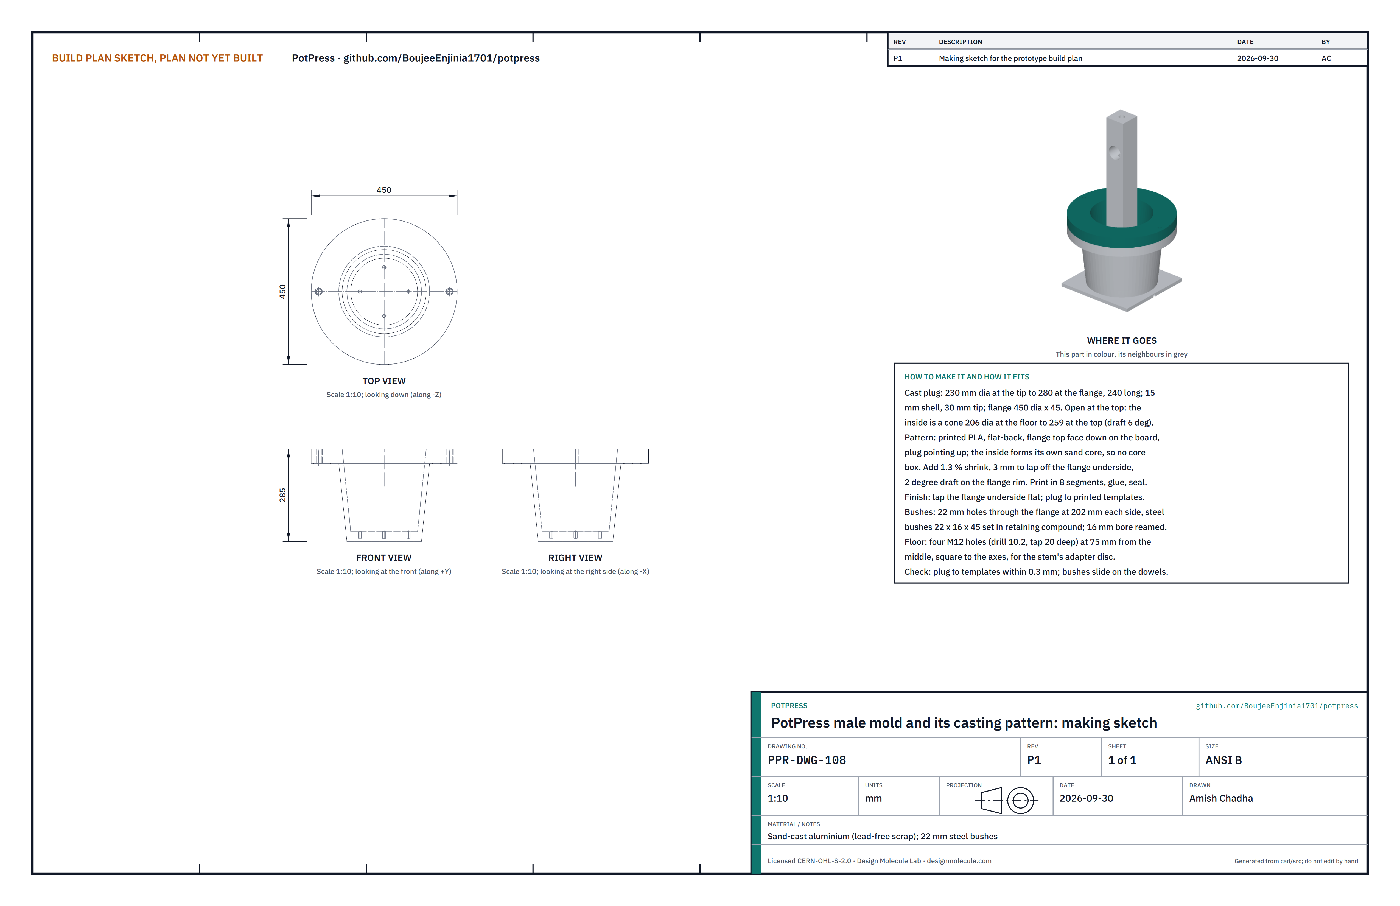
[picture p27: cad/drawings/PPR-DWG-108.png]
Figure 15. Making sketch of the male mold and its pattern


*Figure 15. Male mold making sketch (PPR-DWG-108).*

**What it is and what it is made from.** The upper mold, a plug that forms the inside of the pot. Sand-cast aluminium from lead-free scrap, from a printed pattern; two steel bushes. About 23 kg.

**How to make it.**

1. **Pattern.** Print the plug in PLA, scaled up 1.3 %, with 3 mm extra on the flange underside and 2 degrees of draft on the flange rim. It is 456 mm across and 289 mm tall: 8 pieces on a 250 mm printer. The plug is open at the top: its inside is a cone 206 mm across at the floor and 259 mm at the top, which already has 6 degrees of draft.
2. **Casting.** Flat-backed like the female: flange top face down on the board, plug pointing up; the sand fills the inside as its own core. No core box.
3. **Plug.** Finish to printed templates within 0.3 mm (radius 115 at the tip, 140 at the flange, 240 long).
4. **Stop face.** Lap the flange underside onto the female mold's lapped face: a little valve grinding paste between them, the plug in the cavity, turn the male back and forth a quarter turn at a time until marking blue shows even contact all round.
5. **Dowels and bushes.** Print eight spacer pads exactly 15.0 mm thick, shaped to the wall. Set them round the plug at two heights, lower the male into the female until the flanges meet, and clamp the flanges together. On a pillar drill, drill an 8 mm pilot through the male flange and 30 mm into the female flange at 202 mm each side of the middle on the left-right line. Separate them. Open the male holes to 22 mm right through and set 22 x 16 x 45 mm steel bushes in them with retaining compound. Open the female holes to 15.8 mm, ream 16 mm, and press in 16 x 50 mm hardened dowels, 30 deep, 20 standing proud.
6. **Stem holes.** Four M12 holes in the plug floor (drill 10.2, tap 20 deep) at 75 mm from the middle, on the left-right and front-back lines.

**How it fits the parts next to it.**

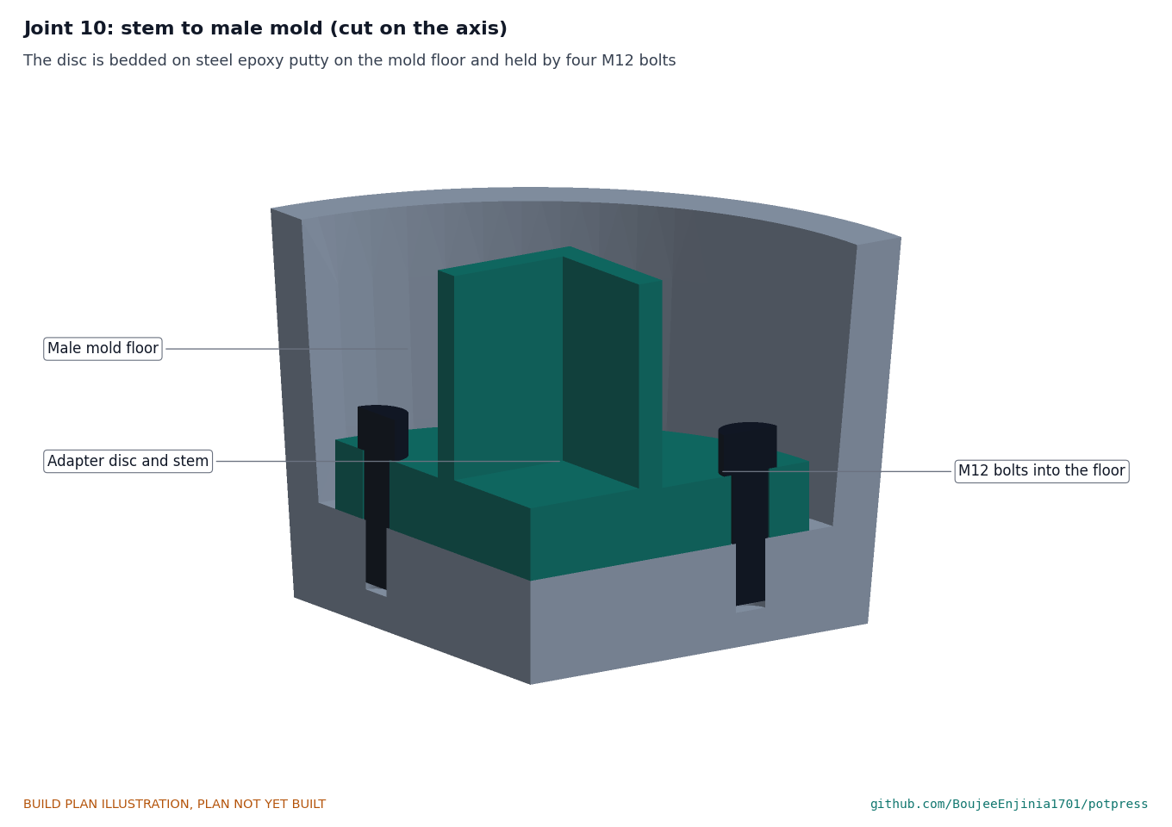
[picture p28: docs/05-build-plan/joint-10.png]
Figure 16. Joint 10: stem to male mold


*Figure 16. Joint 10, cut on the axis. The stem's disc is bedded on steel epoxy putty on the plug floor and held by four M12 bolts.*

The bushes slide over the dowels (Figure 14); the flange lands on the female's stop ring. The stem bolts in from above (step 13).

**Check before moving on.** The plug is within 0.3 mm of the templates; the male drops onto the dowels and lifts off without force; with the spacer pads in, the wall gap is 15 mm, give or take 0.5, all round.

### 3.9 Male mold slide: stem, load pin and crank

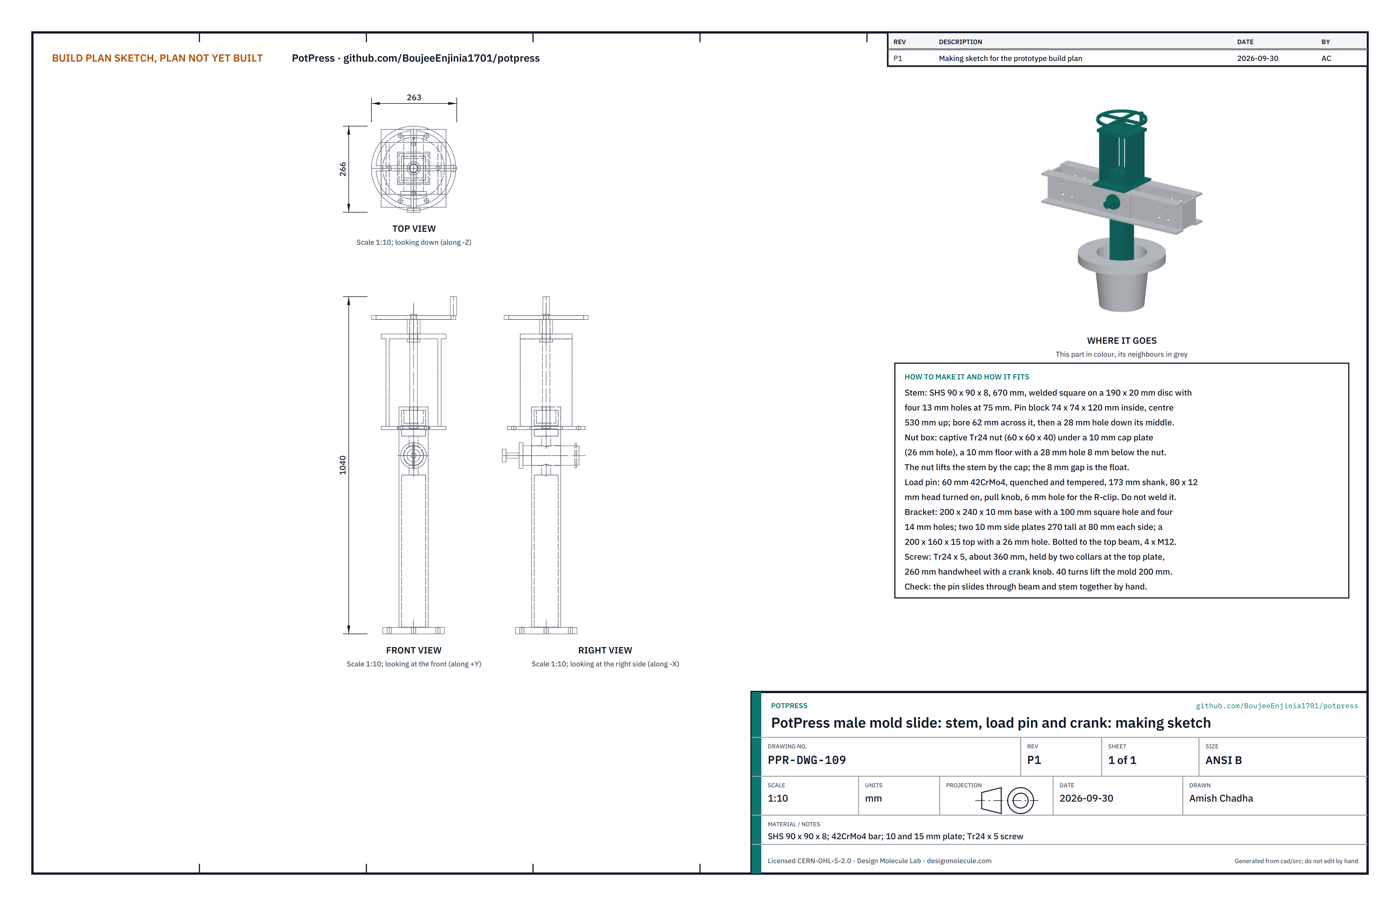
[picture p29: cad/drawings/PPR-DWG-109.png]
Figure 17. Making sketch of the stem, load pin and crank


*Figure 17. Stem, load pin and crank making sketch (PPR-DWG-109).*

**What it is and what it is made from.** The square stem the male mold hangs from, the single pin that locks it to the top crossbeam for pressing, and the hand crank that lifts it 200 mm to open the molds. SHS 90 x 90 x 8 mm tube; 42CrMo4 quenched and tempered bar (pin); 10, 15 and 20 mm plate; bought Tr24 x 5 lead screw with nut, two thrust collars and a 260 mm handwheel.

**How to make it.**

1. **Stem.** Saw the tube to 670 mm, square ends. Weld it square in the middle of a 190 x 20 mm disc; drill four 13 mm holes in the disc at 75 mm from the middle, lined up with the tube's faces.
2. **Pin block.** A 74 x 74 x 120 mm steel block that slides inside the tube. Drill a 28 mm hole down its middle (the lead screw passes through it when the stem is cranked up). Weld it inside the tube with its centre 530 mm above the disc.
3. **Pin bore.** Bore 62 mm across the tube walls and the block at the block's centre, square to two faces (a machine shop, or the magnetic drill used for the top beam).
4. **Nut box.** Weld a 10 mm floor plate, with a 28 mm hole in the middle, inside the tube 58 mm below the top. Drop the Tr24 nut (60 x 60 x 40 mm) in on top of it, then weld a 90 x 90 x 10 mm cap plate with a 26 mm hole on the top of the tube. The nut is now captive with 8 mm of free travel below it.
5. **Load pin.** Turn the 60 mm pin with a 173 mm shank and an 80 x 12 mm head from one piece (do not weld quenched and tempered alloy steel), a pull knob on the head, and a 6 mm cross hole for the R-clip 20 mm from the tail.
6. **Crank bracket.** A 200 x 240 x 10 mm base plate with a 100 mm square hole and four 14 mm holes (matching the top beam); two 10 mm side plates 270 mm tall, 80 mm each side of the middle; a 200 x 160 x 15 mm top plate with a 26 mm hole in the middle.
7. **Screw.** The Tr24 x 5 screw, about 360 mm, is held in the top plate by a collar above and below, with the handwheel on top. 40 turns lift the mold 200 mm; the thread is self-locking, so the mold cannot drop if the wheel is let go.

**How it fits the parts next to it.**

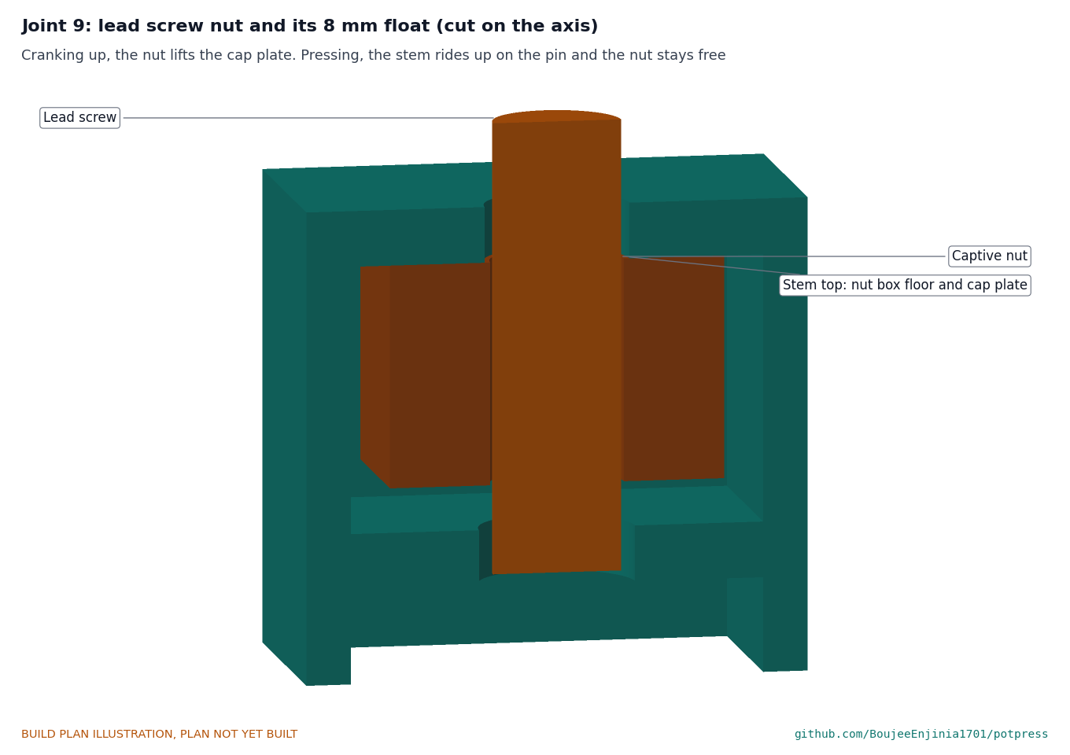
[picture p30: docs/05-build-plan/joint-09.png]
Figure 18. Joint 9: lead screw nut and its float


*Figure 18. Joint 9, cut on the axis. Cranking up, the nut lifts the cap plate; pressing, the stem rides up about 2 mm onto the pin and the nut stays free, so the screw never takes press force.*

**Check before moving on.** The pin slides through the top beam and the stem together by hand when their bores line up; the stem slides between the guides over 200 mm without binding.

### 3.10 Fixed mesh guards

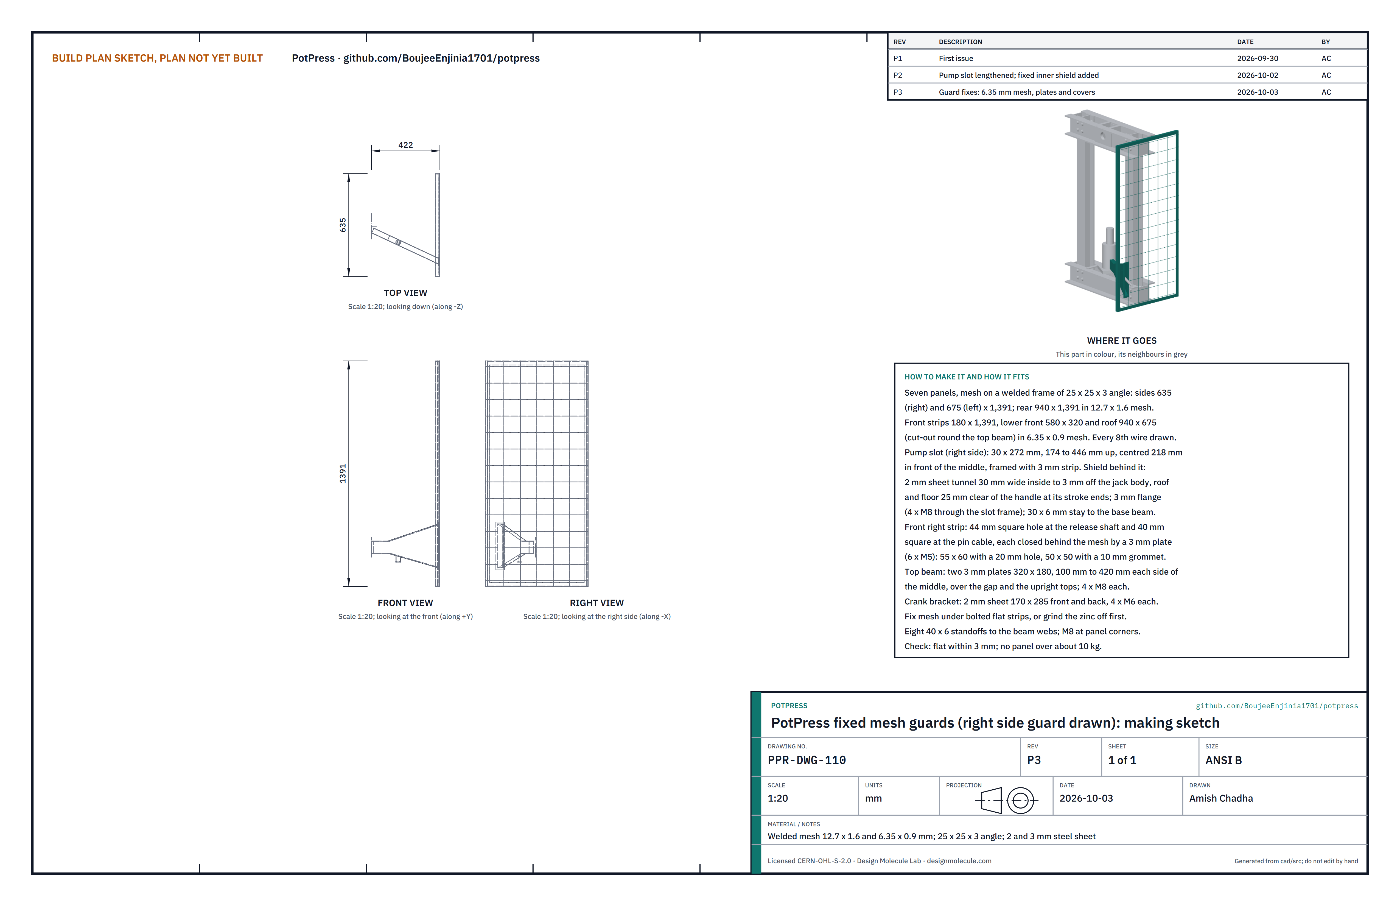
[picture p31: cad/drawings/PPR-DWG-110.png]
Figure 19. Making sketch of the fixed guards


*Figure 19. Fixed guards making sketch (PPR-DWG-110, Rev P3), with the right side guard drawn.*

**What it is and what it is made from.** Seven welded-mesh panels that fence the press on all sides and the top, a fixed steel shield behind the pump slot, and the plates and covers that close the remaining openings (the guard fixes Amish decided on 2026-10-03). Galvanised welded mesh in two sizes: 12.7 x 12.7 x 1.6 mm (half-inch, about 11 mm clear) on the sides and back, which stand 100 mm or more from anything that moves, and 6.35 x 6.35 x 0.9 mm (quarter-inch, about 5.5 mm clear) on the front strips, lower front panel and roof, which stand as close as 39 mm; 25 x 25 x 3 mm steel angle; 40 x 6 mm flat bar; 2 mm and 3 mm steel sheet; 30 x 6 mm flat bar; a rubber grommet.

**How to make it.**

1. Weld a frame of angle for each panel, one leg flat behind the mesh and one pointing inward: right side 635 x 1,391 mm; left side 675 x 1,391; rear 940 x 1,391; two front strips 180 x 1,391; lower front 580 x 320; roof 940 x 675 with a cut-out round the top beam.
2. Fix the mesh to each frame: the 12.7 mm mesh on the two sides and the rear, the 6.35 mm mesh on the two front strips, the lower front panel and the roof. Do not swap them; the finer mesh is what lets the front and roof stand so close to the moving parts. Clamping it under bolted flat strips avoids zinc fume; if you weld it, grind the zinc off at each weld first (safety stop S3).
3. Pump slot in the right side guard: 30 mm wide from 174 to 446 mm up, centred 218 mm in front of the middle. Frame it with 3 mm strip. No brush strip: the shield is the guard.
4. In the right front strip: a 44 mm square opening for the release shaft and a 40 mm square for the pin cable. Close each from behind with a 3 mm steel plate bolted through the mesh with three M5 bolts: for the shaft a 55 x 60 mm plate with a 20 mm hole, butted against the strip's frame, leaving 4 mm round the 12 mm shaft; for the cable a 50 x 50 mm plate with a 10 mm hole and a rubber grommet, leaving 2 mm round the 6 mm cable.
5. Eight standoffs of 40 x 6 mm flat bar, bolted to the outside of the beam webs, reaching out to the side guards.
6. Top beam cover plates: two 3 mm plates 320 x 180 mm. Each lies on the top beam's top flanges from the edge of the crank bracket's base plate (100 mm from the middle) to the beam end, covering the gap between the channels and the open tops of the upright's two channels. Drill and tap the flanges for four M8 bolts per plate.
7. Crank bracket covers: two pieces of 2 mm sheet 170 x 285 mm, screwed with four M6 each into tapped holes in the front and back edges of the bracket's side plates, from the base plate to the top plate, so the bracket is closed on all four sides.
8. Shield behind the pump slot (Figure 20): fold 2 mm sheet into a tunnel 30 mm wide inside, running from the slot along the pump handle's line to the jack. Its roof and floor slope with the handle so that they stand 25 mm clear of it at both ends of its stroke: at the slot the tunnel is as tall as the slot; at the jack end it is 73 mm tall inside, from 266 to 339 mm up. Cut the jack end to the curve of the jack body, 3 mm off it, and the slot end square to the guard. Weld on a 3 mm flange the size of the slot frame, drilled for four M8 bolts through the frame and the mesh. Weld a 30 x 6 mm flat-bar stay under the tunnel floor, 235 mm out from the jack's centre along the handle's line, with a small foot plate that bolts to the base beam's top flange.

**How it fits the parts next to it.**

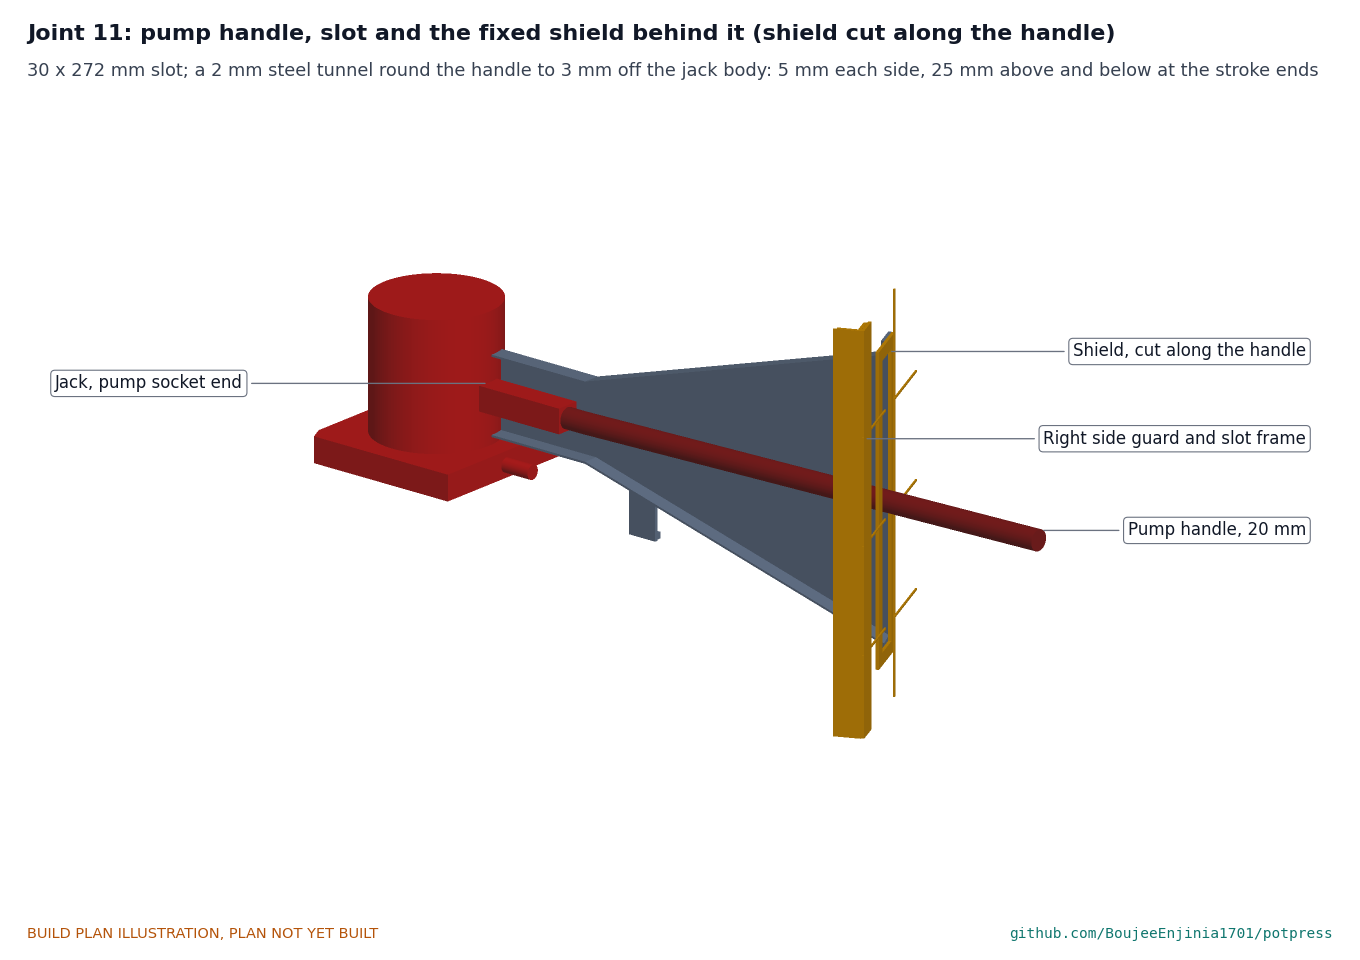
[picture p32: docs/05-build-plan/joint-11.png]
Figure 20. Joint 11: the pump handle passes the right side guard


*Figure 20. Joint 11, with the shield cut along the handle. The handle crosses the guard at 25 degrees, about 2 mm clear of the slot frame each side; inside the tunnel it runs 5 mm from the walls and stops 25 mm short of the roof, the floor and the slot ends at both ends of its stroke. Through the slot only the handle and the end of the jack's pump socket can be reached.*

The side panels bolt to the standoffs; the panels bolt to each other at every corner with M8 bolts. The right front strip sits 40 mm back from the front line, leaving a pocket in front of it for the interlock. The shield's flange bolts behind the slot frame with the mesh between them, and its stay bolts to the base beam; the jack must be in place first, and to take the jack out, unbolt the shield. The small-hole plates go on after the release shaft and the pin cable are threaded through them (step 16). The top beam cover plates and the crank bracket covers go on after the crank is fitted and checked; take them off only with the press at rest and the release open.

**Check before moving on.** Each panel flat within 3 mm and no heavier than about 10 kg; no loose or sharp wire ends. The 6.35 mm mesh is on the front strips, the lower front panel, the roof and the gate. The shield's inside is 30 mm wide along its length and its jack end stands 3 mm off the jack body all round. No gap of more than 4 mm round the release shaft or 2 mm round the cable; no opening into the top beam or the crank bracket.

### 3.11 Front gate

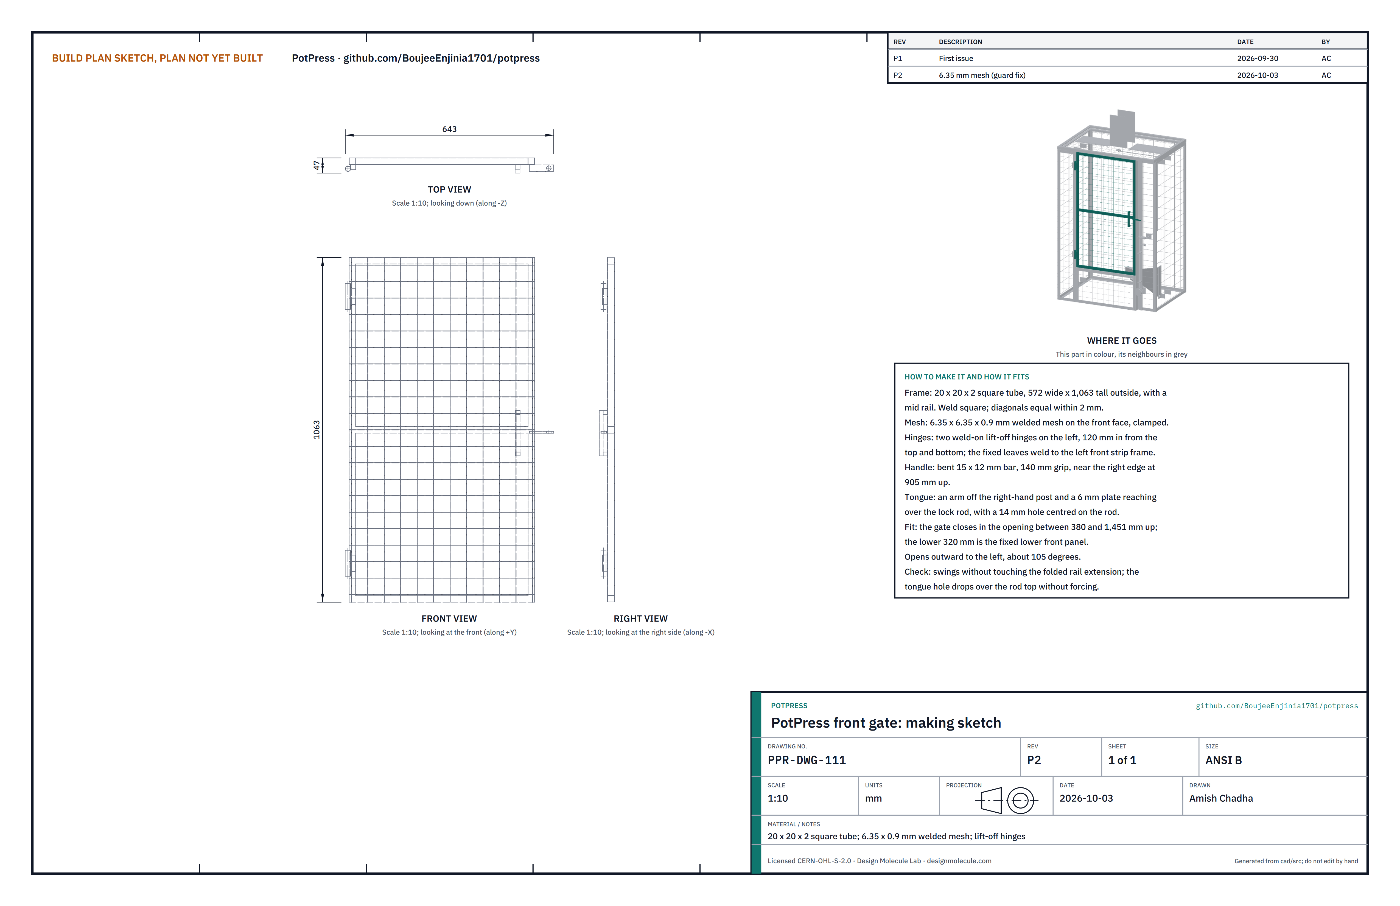
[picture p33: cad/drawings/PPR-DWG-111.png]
Figure 21. Making sketch of the front gate


*Figure 21. Front gate making sketch (PPR-DWG-111, Rev P2).*

**What it is and what it is made from.** The hinged mesh door the operator opens to load and unload. 20 x 20 x 2 mm square tube; 6.35 x 6.35 x 0.9 mm welded mesh, the finer mesh of the front panels; two weld-on lift-off hinges; a bent bar handle; 6 mm plate.

**How to make it.**

1. Weld a 572 x 1,063 mm frame of tube with a mid rail; diagonals equal within 2 mm.
2. Fix the 6.35 mm mesh on the front face.
3. Weld the gate leaves of two lift-off hinges to the left post, 120 mm in from the top and bottom.
4. Weld the pull handle near the right edge, 905 mm up.
5. Tongue: an arm off the right-hand post and a 6 mm plate that reaches over the lock rod, with a 14 mm hole centred on the rod.

**How it fits the parts next to it.** The gate closes the opening from 380 to 1,451 mm up between the front strips and opens outward to the left, about 105 degrees. With the gate shut and the valve closed, the lock rod stands through the tongue's hole (Figure 24).

**Check before moving on.** It swings without touching the folded rail extension; the tongue hole drops over the rod without forcing.

### 3.12 Gate and pin interlock

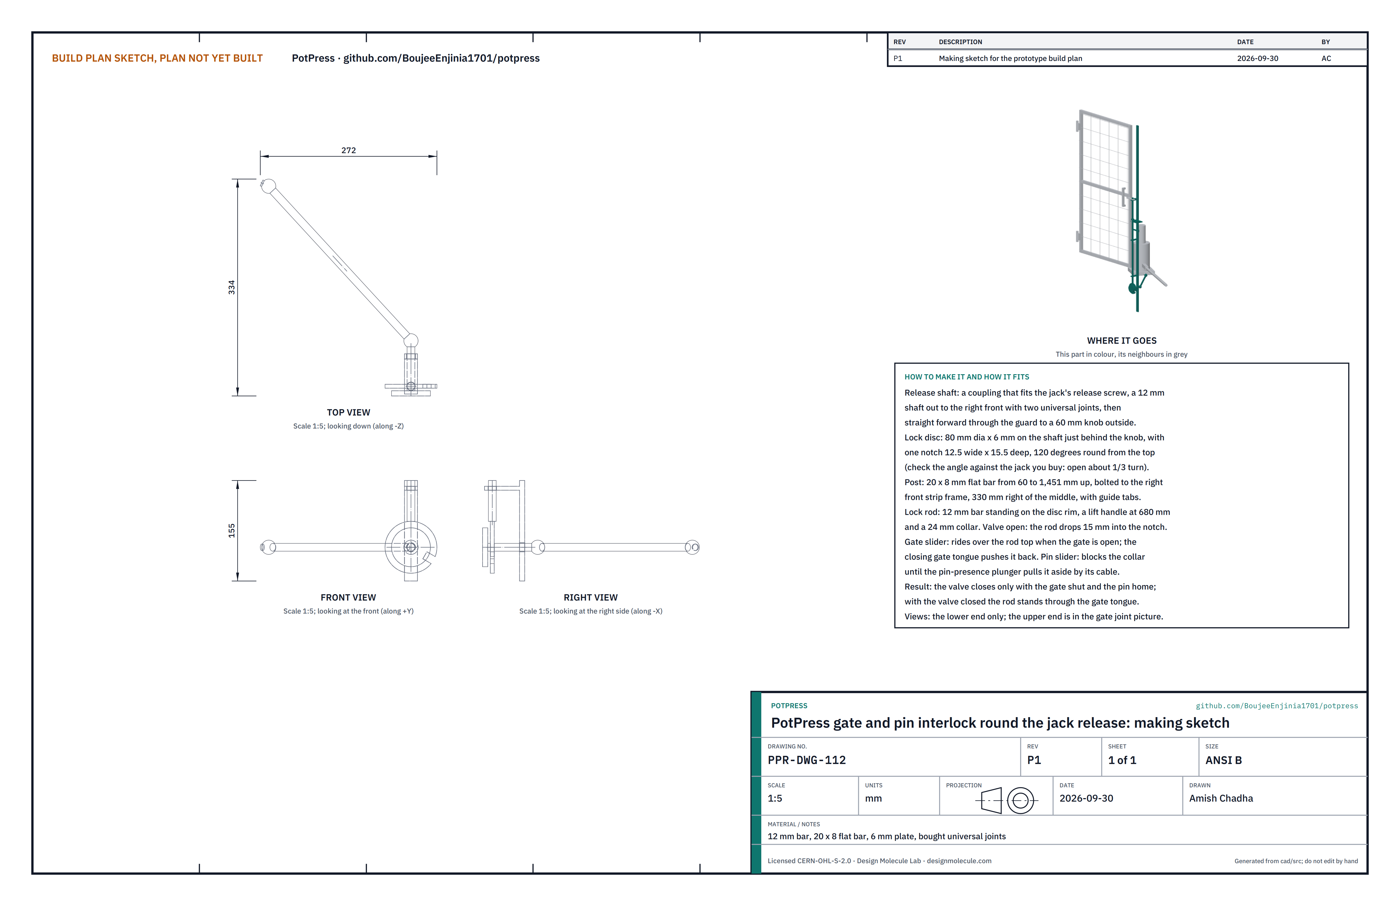
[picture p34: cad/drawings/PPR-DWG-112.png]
Figure 22. Making sketch of the interlock


*Figure 22. Interlock making sketch (PPR-DWG-112); the views show the lower end.*

**What it is and what it is made from.** A purely mechanical lock round the jack's release valve: the valve can be closed (so the jack can build pressure) only with the gate shut and the load pin fully home, and the gate cannot be opened while the valve is closed. 12 mm steel bar; 20 x 8 mm flat bar; 6 mm plate; two bought universal joints; springs; a push-pull cable.

**How to make it.**

1. **Coupling.** Buy the jack first. Make a coupling that fits over its release screw (most take the slotted end of the pump handle; a tube with a cross pin or a tongue that fits the slot will do).
2. **Release shaft.** 12 mm bar from the coupling out to the right front, two universal joints, then straight forward through the front right strip to a 60 mm knob just outside the guard.
3. **Lock disc.** 80 mm across and 6 mm thick, fixed on the shaft just behind the knob, with one notch 12.5 mm wide and 15.5 mm deep. Set the notch so it comes to the top when the valve has been opened about a third of a turn (check this on the jack you have).
4. **Post.** 20 x 8 mm flat bar from 60 to 1,451 mm up, 330 mm right of the middle, bolted to the right front strip's frame, with guide tabs at 330, 600, 742 and 899 mm up.
5. **Lock rod.** 12 mm bar from the disc rim up through the tabs to 920 mm, with a lift handle at 680 mm and a 24 mm collar at 757 mm.
6. **Gate slider.** A small plate that a spring pushes over the top of the rod when the gate opens; the closing gate's tongue pushes it back.
7. **Pin slider.** A notched plate under the collar that a spring pushes into the rod's path. A plunger on the top beam rests on the load pin's head; when the pin is fully home, the plunger lifts and pulls the slider aside through the push-pull cable.

**How it fits the parts next to it.**

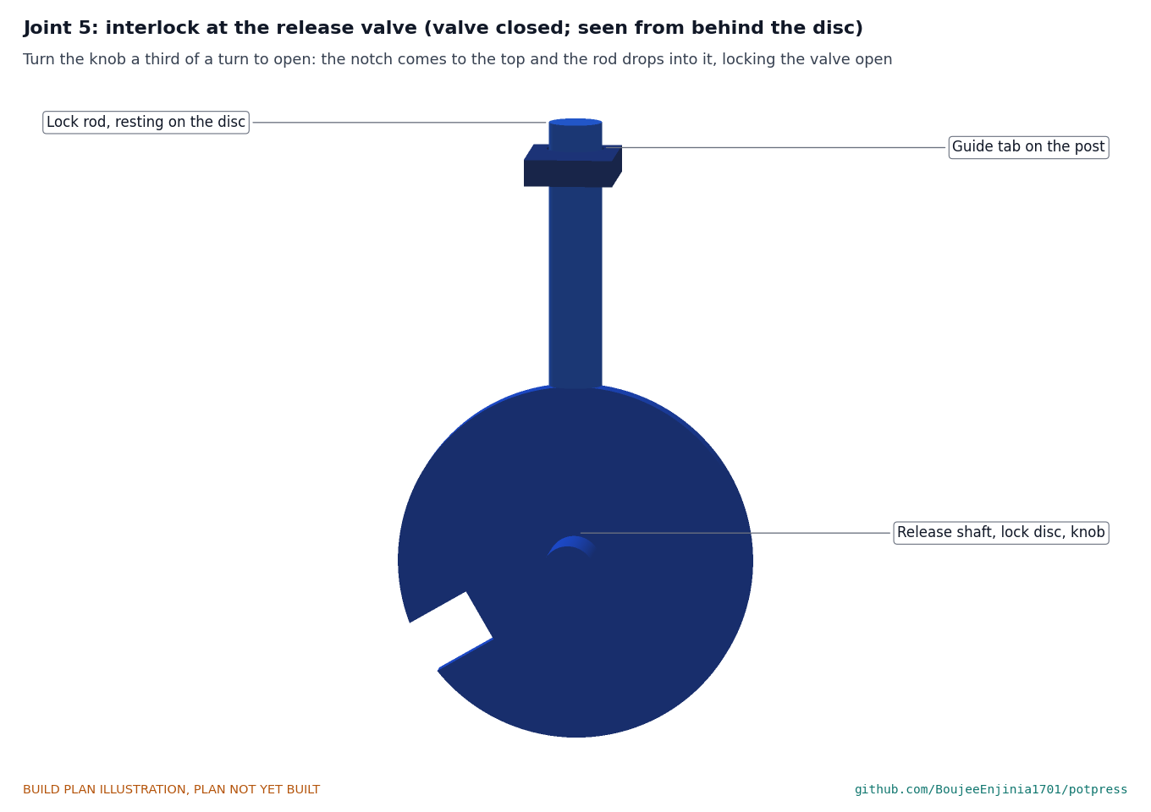
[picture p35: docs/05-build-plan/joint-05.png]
Figure 23. Joint 5: interlock at the release valve


*Figure 23. Joint 5, seen from behind the disc, valve closed. Turning the knob a third of a turn to open brings the notch to the top; the rod drops into it and the valve is locked open.*

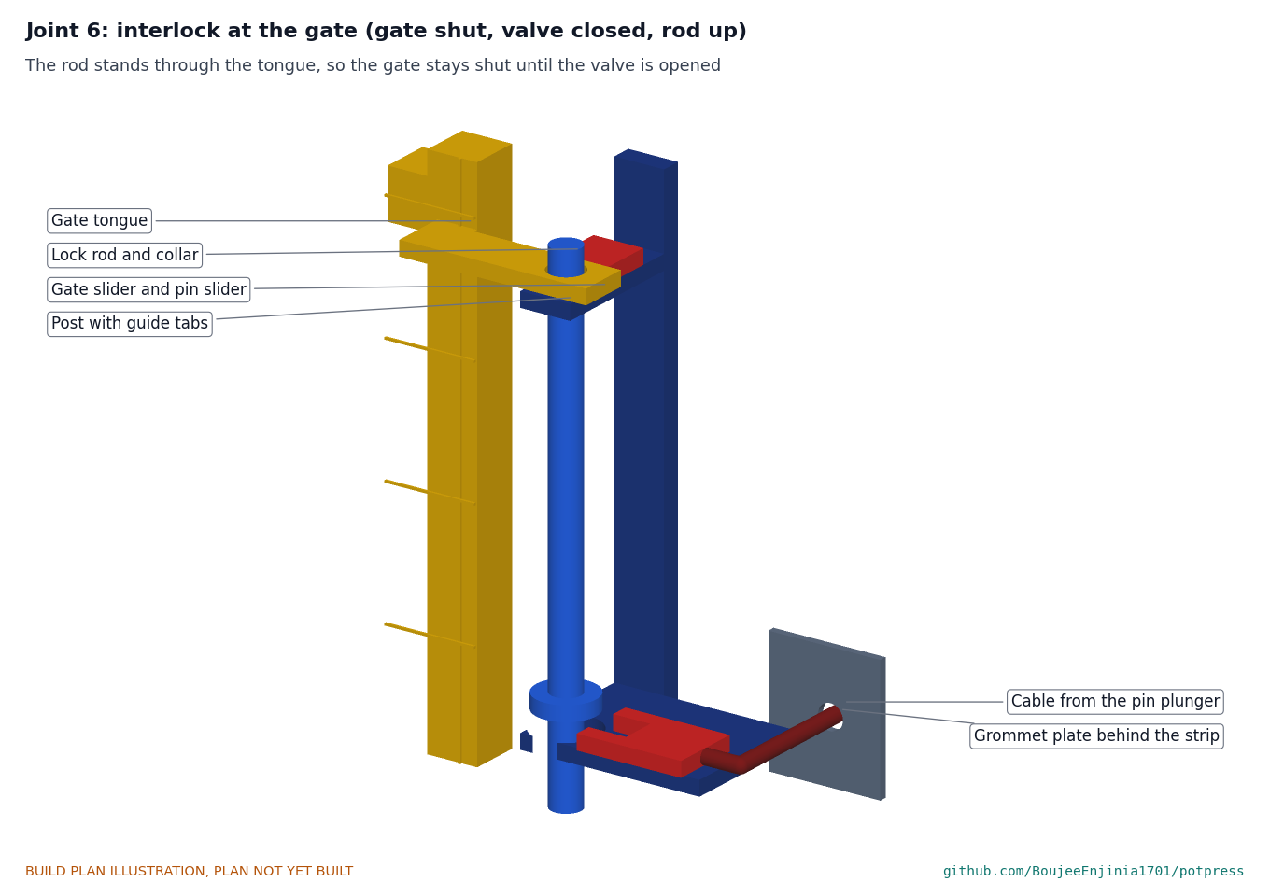
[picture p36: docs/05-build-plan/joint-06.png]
Figure 24. Joint 6: interlock at the gate


*Figure 24. Joint 6, gate shut, valve closed, rod up. The rod stands through the gate tongue, so the gate stays shut until the valve is opened.*

In use: open the valve, and the rod drops into the notch (valve locked open, gate free). To close the valve you must lift the rod out of the notch, which the gate slider blocks unless the gate is shut and the pin slider blocks unless the pin is home. With the rod lifted, turn the knob to close; the rod rides on the disc rim and stands through the gate tongue.

**Check before moving on.** See the interlock checks in section 5, done with the jack's release valve open and no pressure.

### 3.13 QC flow-test rack

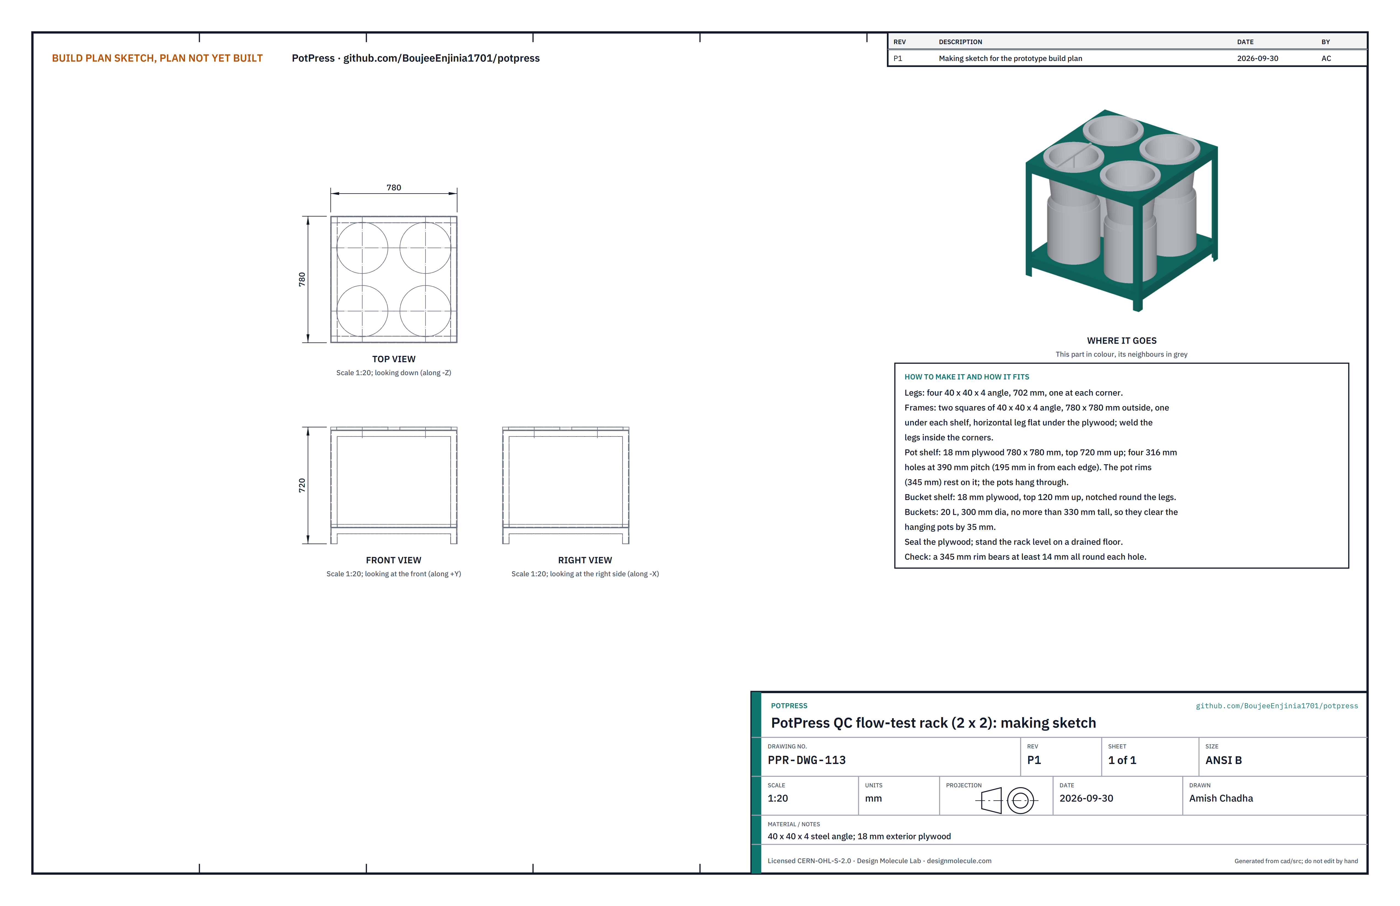
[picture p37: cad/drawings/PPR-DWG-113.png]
Figure 25. Making sketch of the QC rack


*Figure 25. QC rack making sketch (PPR-DWG-113).*

**What it is and what it is made from.** A stand that holds four fired pots, full of water, over four buckets for the one-hour flow test. 40 x 40 x 4 mm steel angle; 18 mm exterior plywood.

**How to make it.**

1. Weld two square frames of angle, 780 x 780 mm outside, horizontal leg flat on top.
2. Weld four legs of angle 702 mm long inside the corners, one frame at the top and one with its top 102 mm up.
3. Pot shelf: 780 x 780 mm plywood with four 316 mm holes at 390 mm centres, 195 mm in from each edge; its top is 720 mm up.
4. Bucket shelf: 780 x 780 mm plywood notched round the legs; its top is 120 mm up.
5. Seal the plywood.

**How it fits the parts next to it.** The pot rims (345 mm) rest on the pot shelf and the pots hang through the holes; 20 L buckets no taller than 330 mm stand under them with 35 mm to spare.

**Check before moving on.** A 345 mm rim bears at least 14 mm all round each hole; the rack stands level.

### 3.14 Printed T-gauge (make 4)

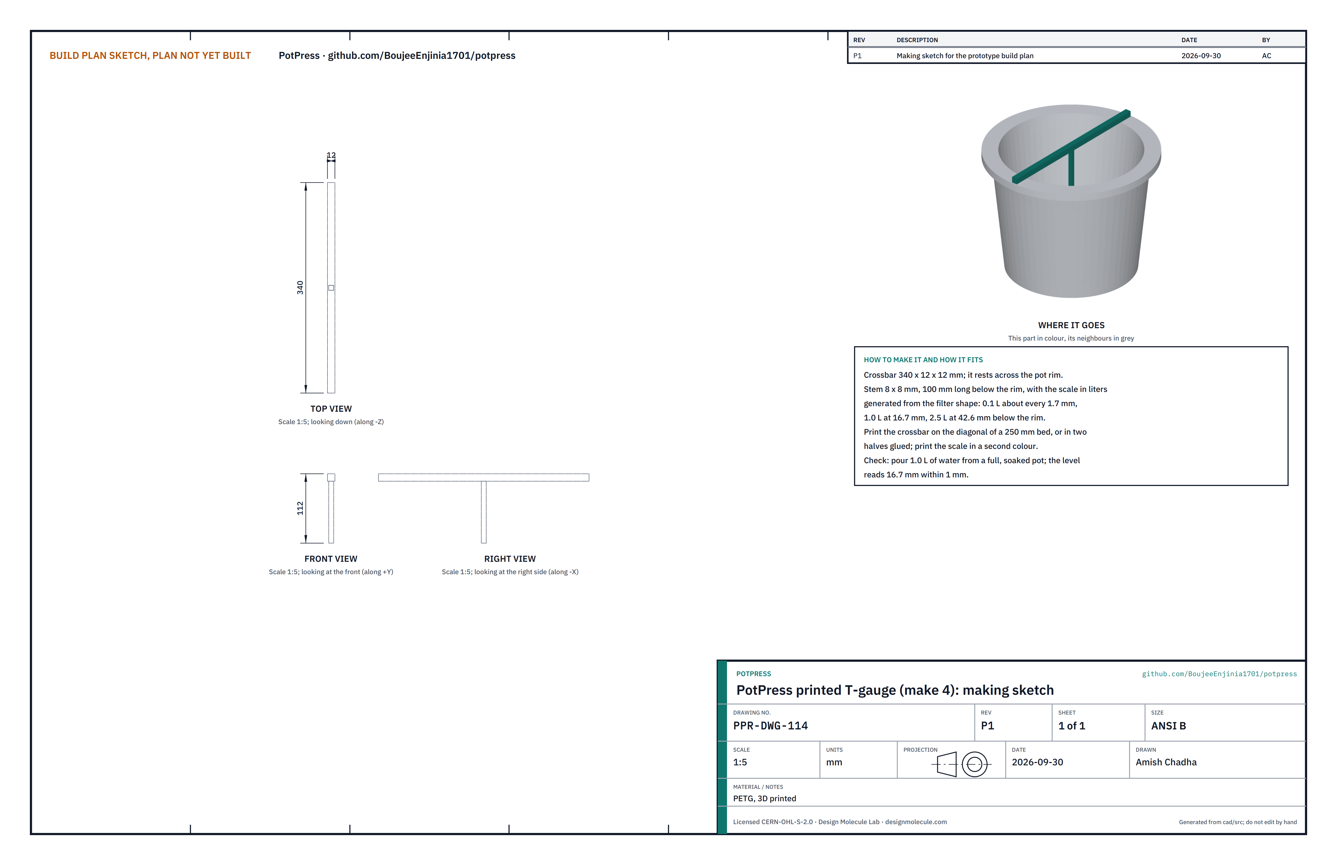
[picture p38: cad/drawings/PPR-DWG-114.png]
Figure 26. Making sketch of the T-gauge


*Figure 26. T-gauge making sketch (PPR-DWG-114).*

**What it is and what it is made from.** A dipstick that rests across a pot's rim and reads how much water has passed in the hour. PETG, printed.

**How to make it.** Print a 340 x 12 x 12 mm crossbar and an 8 x 8 mm stem 100 mm long below it, with the scale in litres: 0.1 L about every 1.7 mm, 1.0 L at 16.7 mm and 2.5 L at 42.6 mm below the rim. Print the crossbar on the diagonal of a 250 mm bed, or in two halves glued; print the scale in a second colour.

**Check before moving on.** From a pot filled to 10 mm below the rim, draw off exactly 1.0 L; the level reads 16.7 mm within 1 mm.

### 3.15 Bought components

Buy to specification, not brand. Line numbers are those of the bill of materials.

- **Bottle jack (line 4).** 20 t hydraulic bottle jack, about 150 mm stroke and 60 mm ram, base about 160 mm square, with its release screw on the same side as the pump socket, and a pump handle at least 700 mm long and about 20 mm across (or a 20 mm tube extension). Buy it before making the jack plate blocks and the interlock coupling.
- **Return springs (line 6).** Two tension springs, about 300 N each, free length under 250 mm, stretching to about 360 mm between hook ends with the platen up.
- **Joint bolts (line 2).** 16 x M16 x 150 grade 10.9 bolts with nuts and 32 hardened washers.
- **Lead screw set (line 10).** Tr24 x 5 screw about 360 mm with its nut (60 mm square or turned to fit the 74 mm stem bore), two thrust collars and a 260 mm handwheel with a crank knob.
- **Dowels and bushes (lines 8 and 9).** Two 16 x 50 mm hardened dowel pins; two 22 x 16 x 45 mm steel bushes.
- **Floor anchors and fixings (lines 1 and 18).** Four M12 anchors for 80 mm in concrete; M12 bolts, nuts and washers for the studs, jack plate and bracket; M8 bolts for the guards and cup; M6 countersunk screws for the guides.
- **Universal joints, springs and push-pull cable (line 21).** Two 12 mm universal joints; small compression springs for the sliders; a push-pull cable about 1 m.
- **Mesh and hinges (lines 16 and 20).** 12.7 x 12.7 x 1.6 mm galvanised welded mesh, about 5 m² from a 1.2 m roll; two pairs of weld-on lift-off hinges; two weld-on barrel hinges (line 7).
- **QC items (lines 14, 17 and 19).** Four 20 L food-grade buckets, 300 mm across and no more than 330 mm tall; release liners, wire trim tool and sponge; kitchen timer and a 0 to 50 °C thermometer.
- **Consumables (line 18).** E6013 electrodes, grinding discs, steel-filled epoxy putty, marking blue, valve grinding paste, wet-and-dry paper, lead-free primer and paint (never on mold faces).

## 4. Putting it together

In each picture the parts already fitted are grey and the part being fitted is in colour, with an arrow showing the way it goes in. Two people throughout; a hoist for the platen and the top crossbeam.

### Step 1: set out and anchor the feet

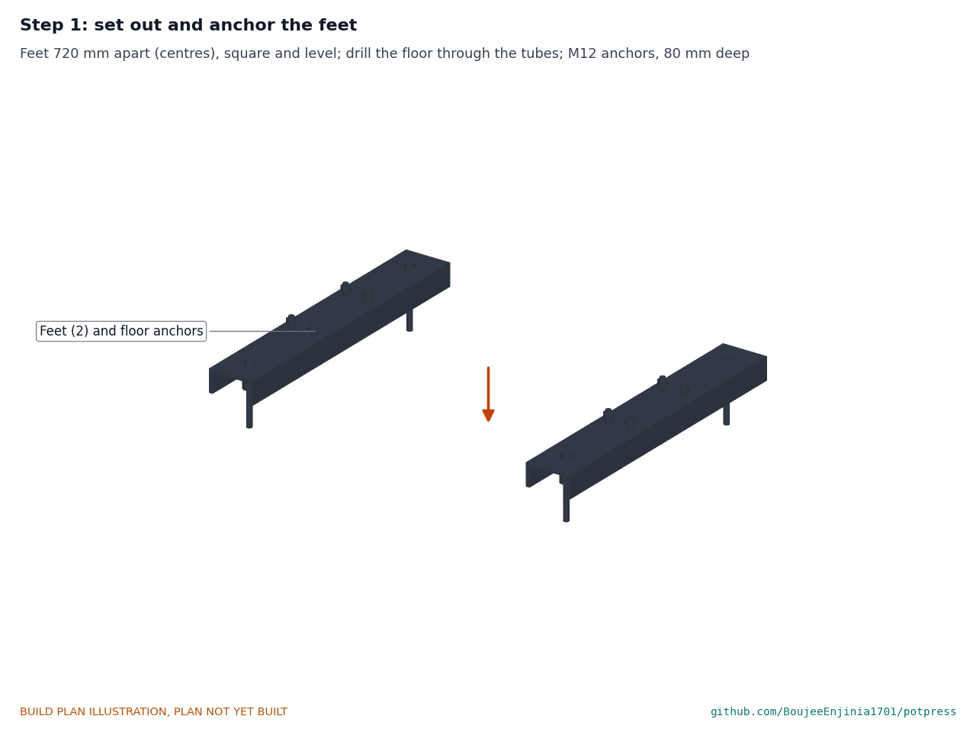
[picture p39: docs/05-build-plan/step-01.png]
Step 1


Place the feet 720 mm apart between centres, parallel and square, and level them with steel shims. Drill the floor through the anchor tubes and fit the four M12 anchors, 80 mm deep, to the anchor maker's torque.

### Step 2: base beam onto the feet

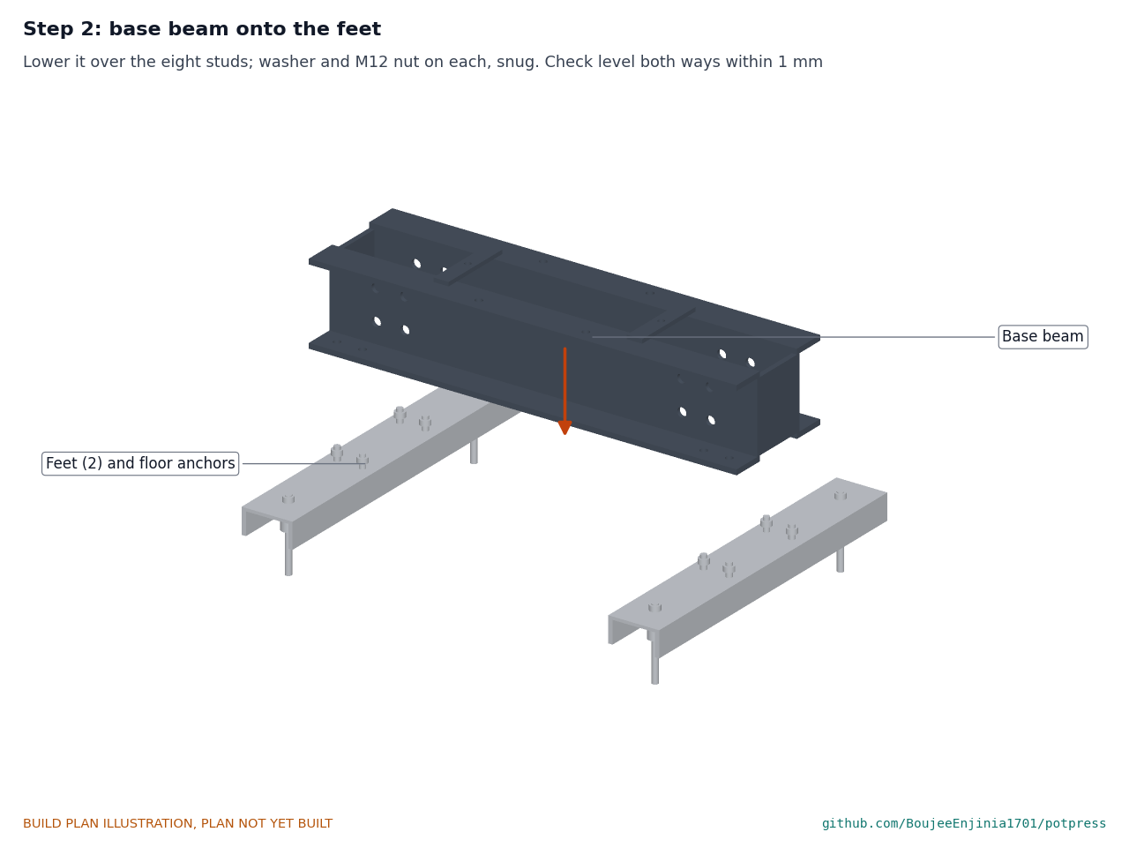
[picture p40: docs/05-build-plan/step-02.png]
Step 2


Lower the beam over the eight studs (Figure 4). A washer and M12 nut on each, snug. Check level both ways within 1 mm.

### Step 3: jack plate and jack

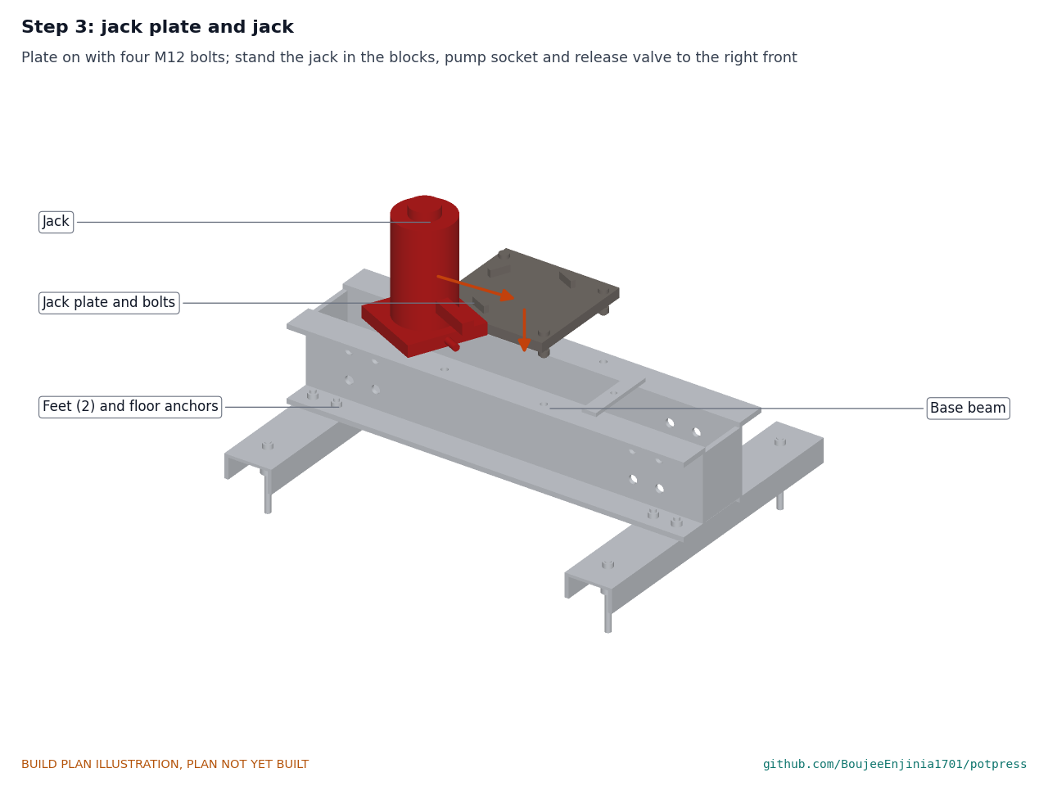
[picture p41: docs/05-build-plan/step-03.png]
Step 3


Bolt the jack plate on with four M12 bolts, nuts under the flanges. Stand the jack in its blocks with the pump socket and release valve to the right front (Figure 5).

### Step 4: uprights into the base beam

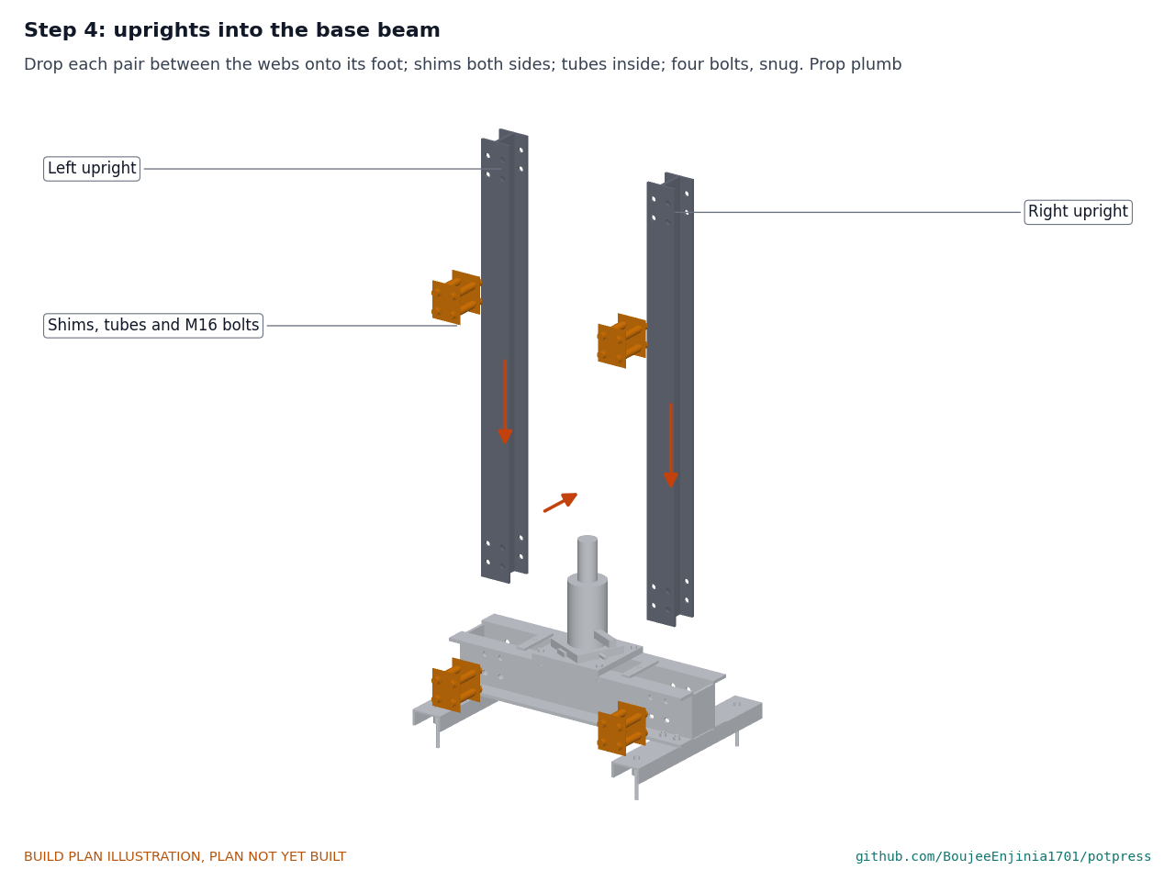
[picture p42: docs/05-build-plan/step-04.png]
Step 4


Stand each upright pair on its foot between the beam webs, with a shim each side and the spacer tubes inside, and fit four M16 bolts (Figure 7), snug only. Prop the uprights plumb.

### Step 5: platen over the uprights

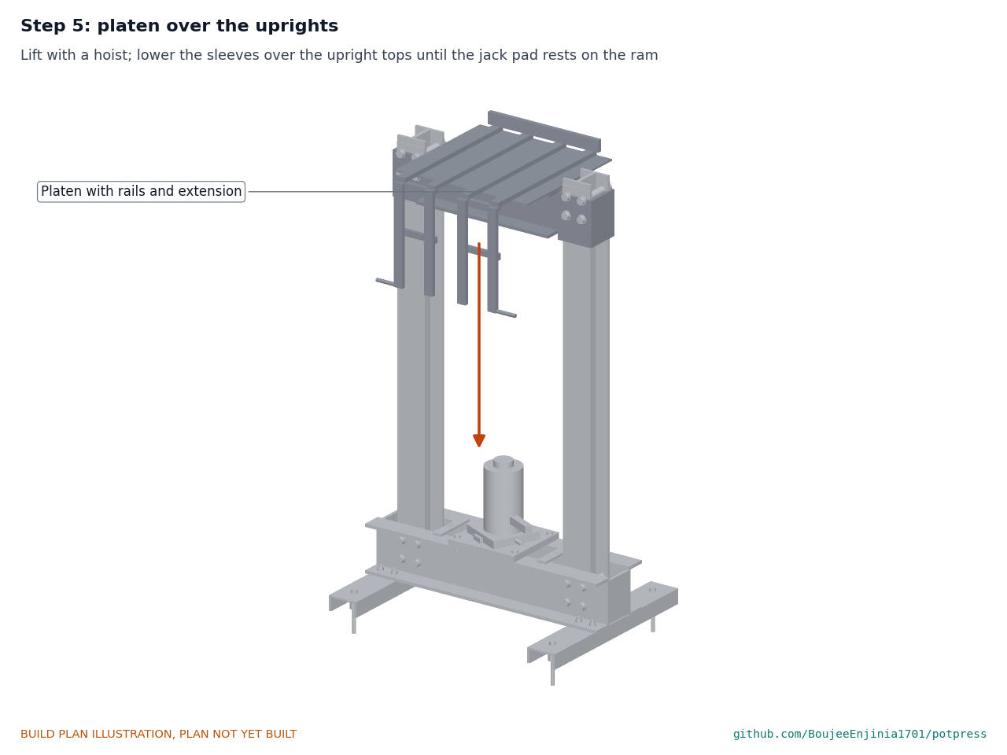
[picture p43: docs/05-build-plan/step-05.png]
Step 5


**Hold point:** safety stop S4. Hoist the platen above the uprights and lower its sleeves over them until the jack pad rests on the ram, fully down.

### Step 6: return springs

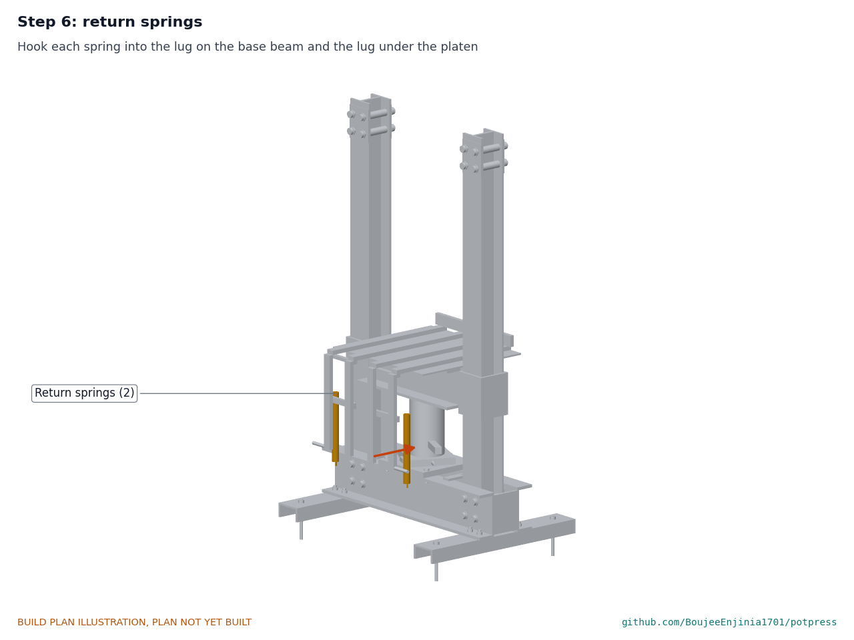
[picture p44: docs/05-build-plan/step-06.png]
Step 6


Hook each spring into the lug on the base beam and the lug under the platen.

### Step 7: stand the stem on the rails

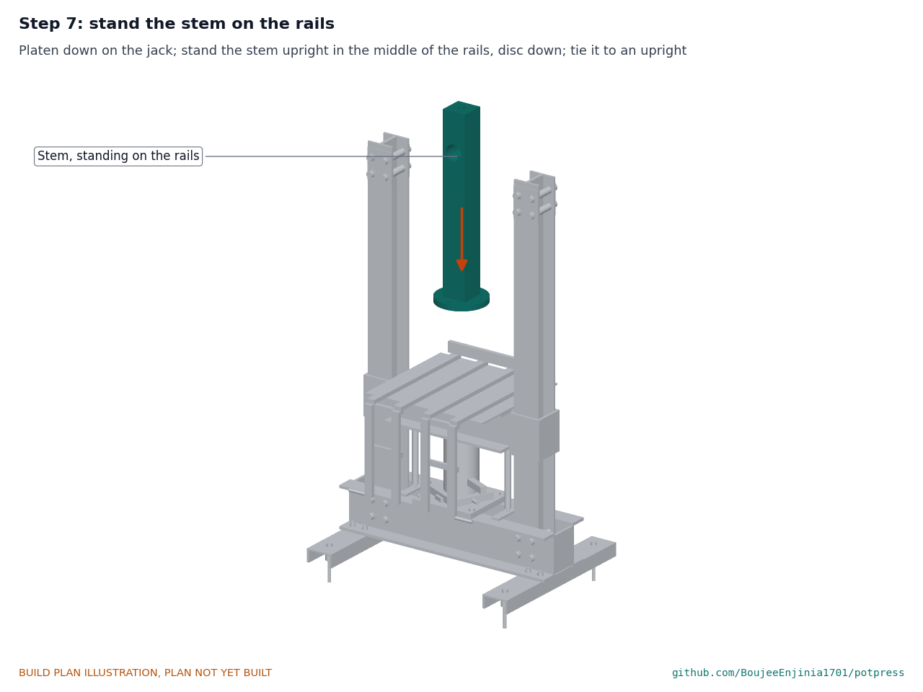
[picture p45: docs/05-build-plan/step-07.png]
Step 7


With the platen fully down, stand the stem upright on its disc in the middle of the rails and tie it to an upright. It must go in now: its disc is too big to pass through the top beam later.

### Step 8: top crossbeam onto the uprights

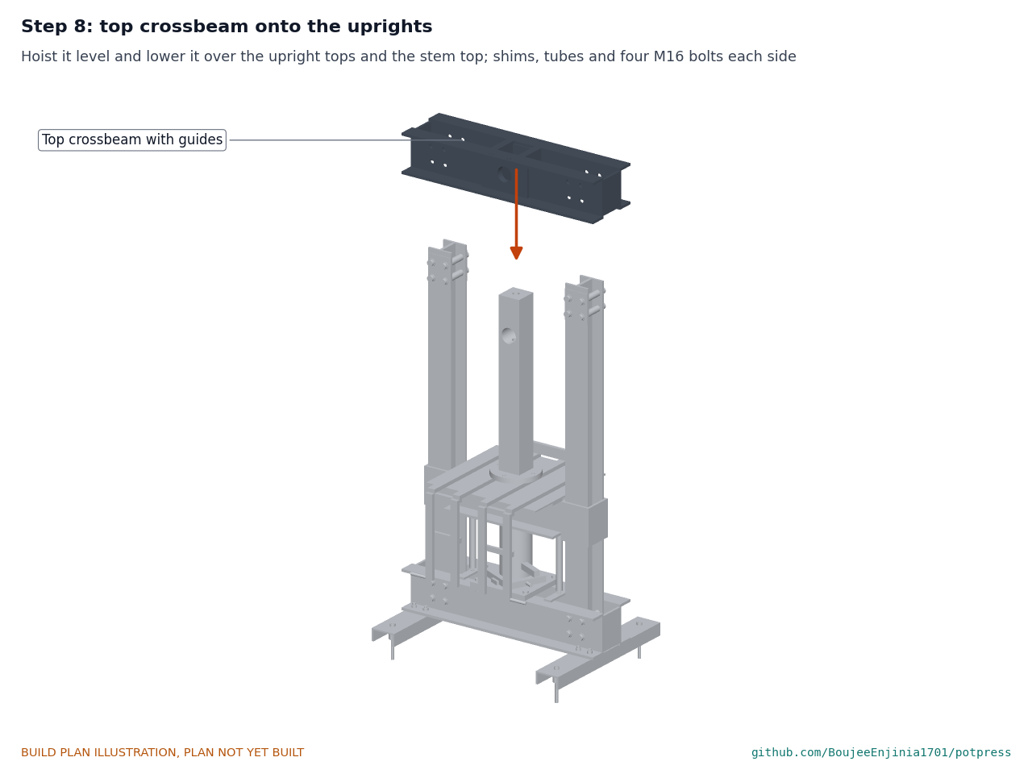
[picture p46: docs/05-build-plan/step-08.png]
Step 8


Hoist the top beam level and lower it over the upright tops, letting the stem's top slide up between its guides. Fit shims, spacer tubes and four M16 bolts each side. Check the uprights plumb within 1 mm per metre and the frame's diagonals equal within 2 mm, then tighten all 16 joint bolts to the bolt maker's torque for M16 grade 10.9. **Hold point:** safety stop S5.

### Step 9: lift the stem, pin it, fit the crank

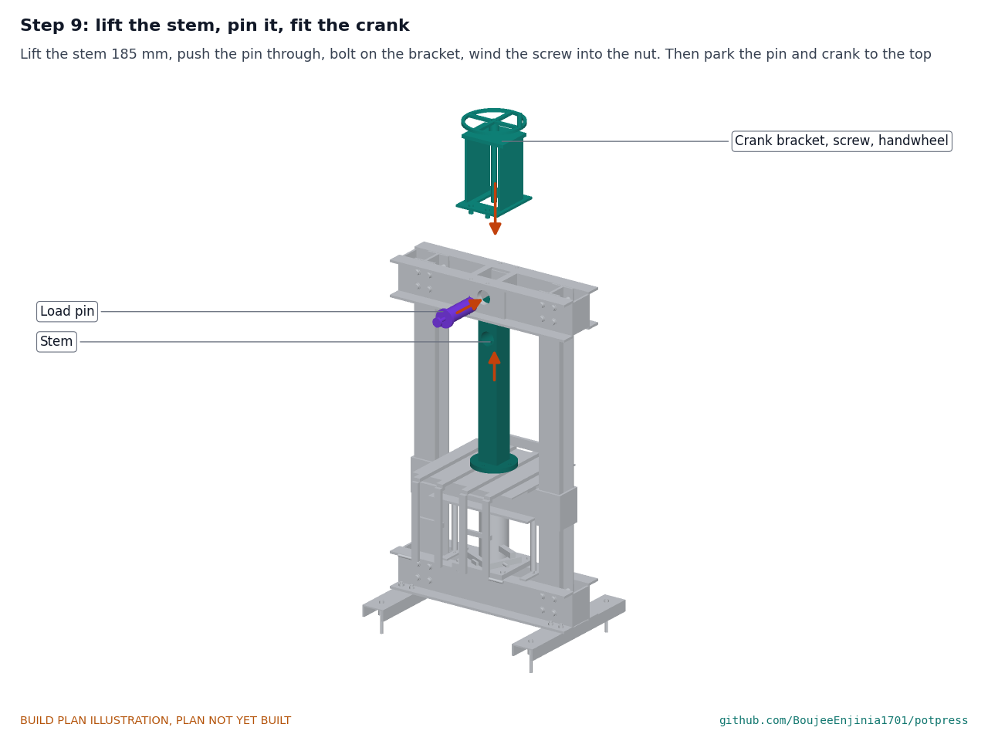
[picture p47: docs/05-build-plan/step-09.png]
Step 9


Lift the stem 185 mm until its bore lines up with the top beam's, and push the load pin through with its R-clip. Bolt the crank bracket to the top beam with four M12 bolts and wind the lead screw down into the nut. Then pull the R-clip, draw the pin out 150 mm to its parked position (it stays in the front bores), and crank the stem to the top: 40 turns.

### Step 10: carriage and female mold, out on the extension

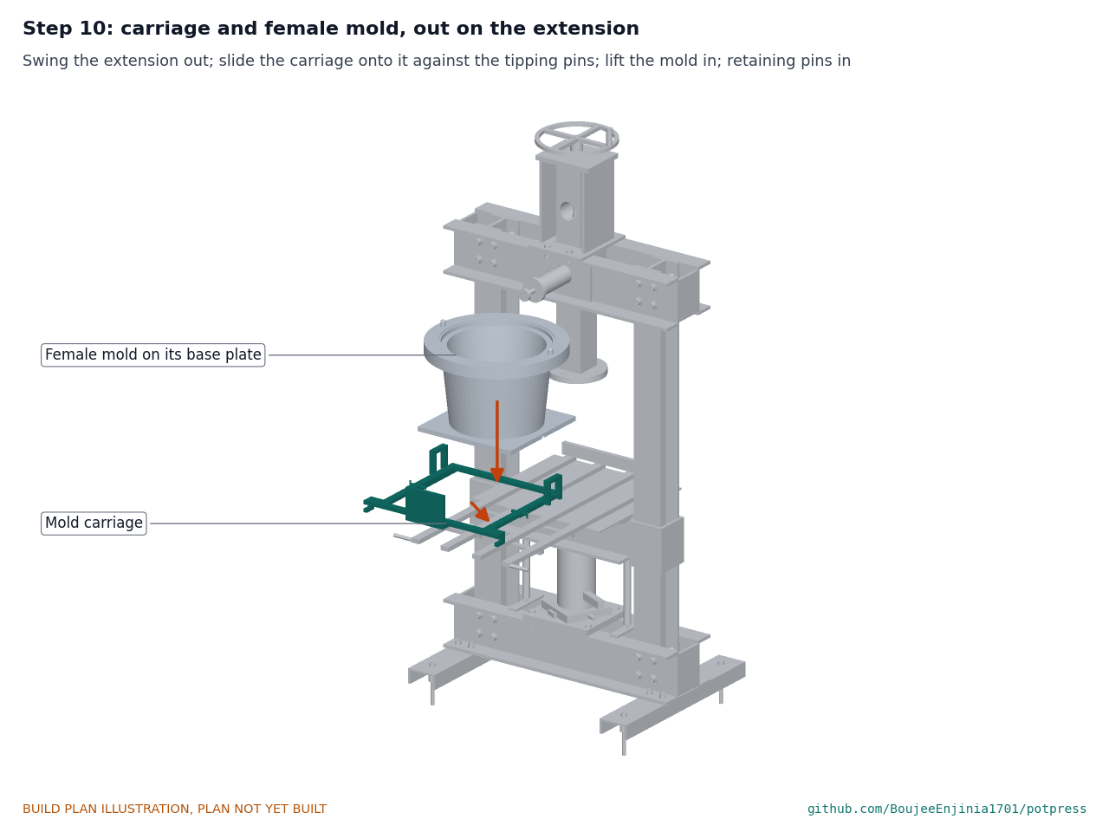
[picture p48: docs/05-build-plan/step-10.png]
Step 10


Swing the extension out. Slide the carriage onto the rails and out until its hooks meet the tipping pins. Two people lift the female mold (36.5 kg) into the carriage; fit both retaining pins.

### Step 11: male mold onto the female mold

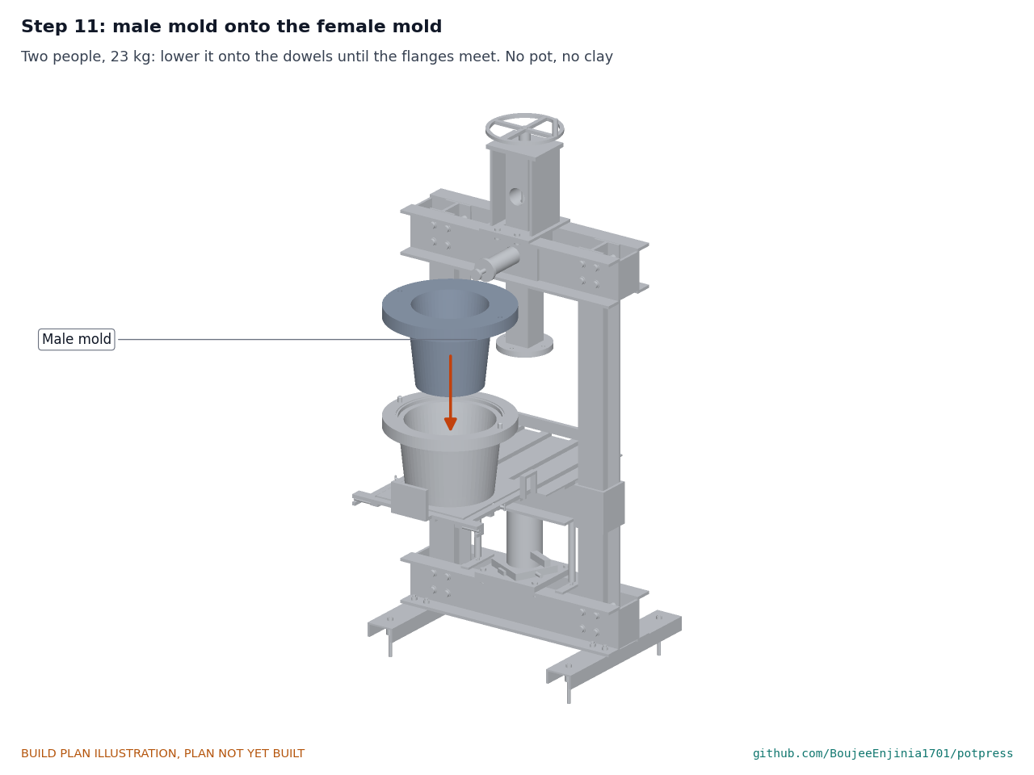
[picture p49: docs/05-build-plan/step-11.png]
Step 11


Two people lower the male mold (23 kg) onto the dowels until the flanges meet. No pot, no clay. Then spread a 3 mm layer of slow-setting steel-filled epoxy putty (at least 30 minutes working time) on the plug floor inside, and go straight on to steps 12 and 13.

### Step 12: slide the molds in, crank down, pin

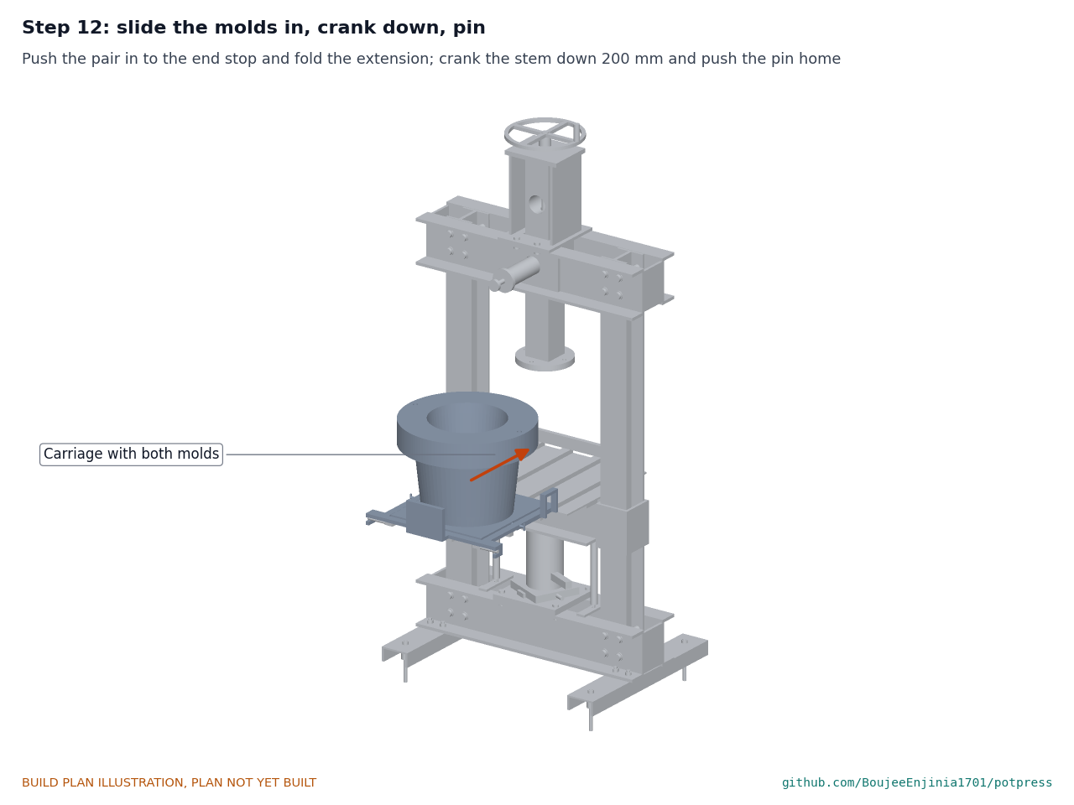
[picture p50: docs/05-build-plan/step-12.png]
Step 12


Push the carriage with both molds in to the end stop (the male's top clears the raised stem by about 55 mm) and fold the extension down. Crank the stem down 200 mm and push the pin fully home with its R-clip.

### Step 13: jack up and bolt the male mold to the stem

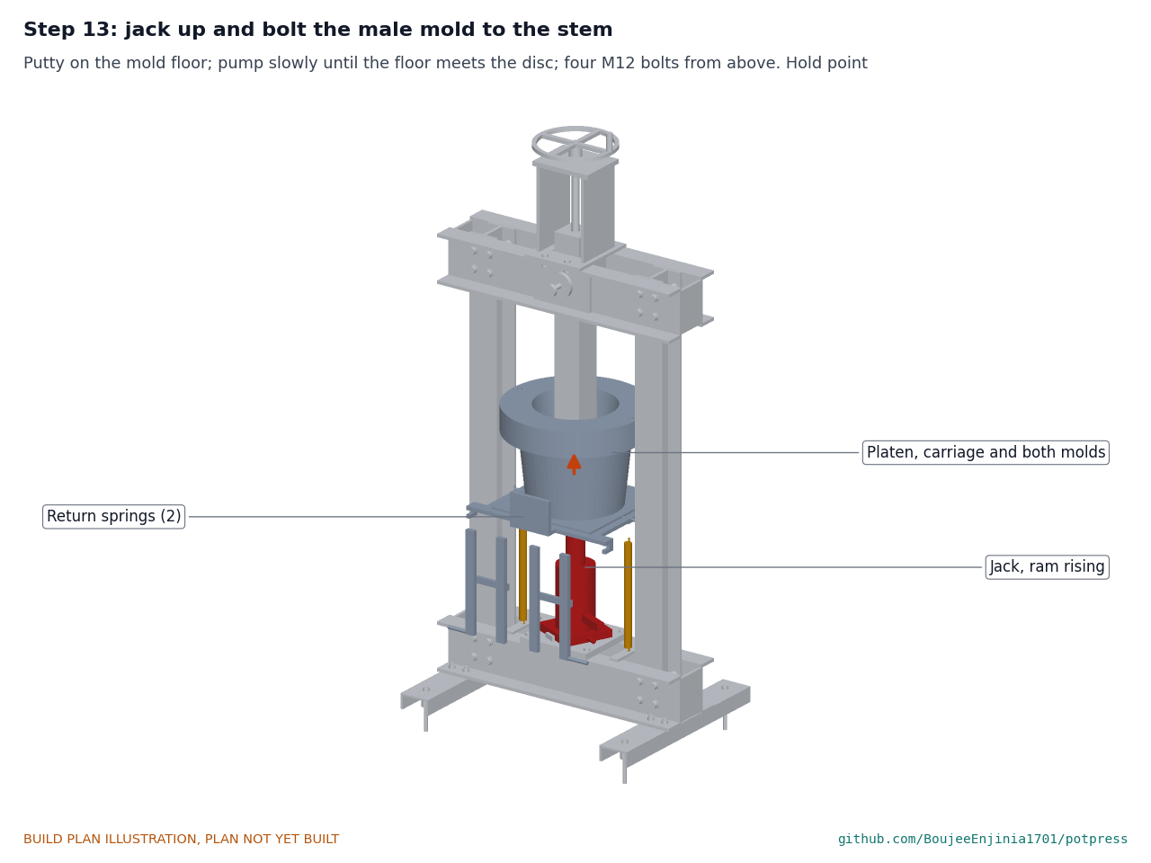
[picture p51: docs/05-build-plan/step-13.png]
Step 13


**Hold point:** safety stop S6. Pump the jack slowly by hand until the plug floor just meets the stem's disc (about 110 mm of ram travel), and stop. Put the four M12 bolts down through the disc into the floor (a long extension through the open top of the plug) and tighten. Let the putty cure, then open the release valve and let the platen down. Crank the male mold up and down its full 200 mm to check it runs free.

### Step 14: fixed guards, shield, plates and covers

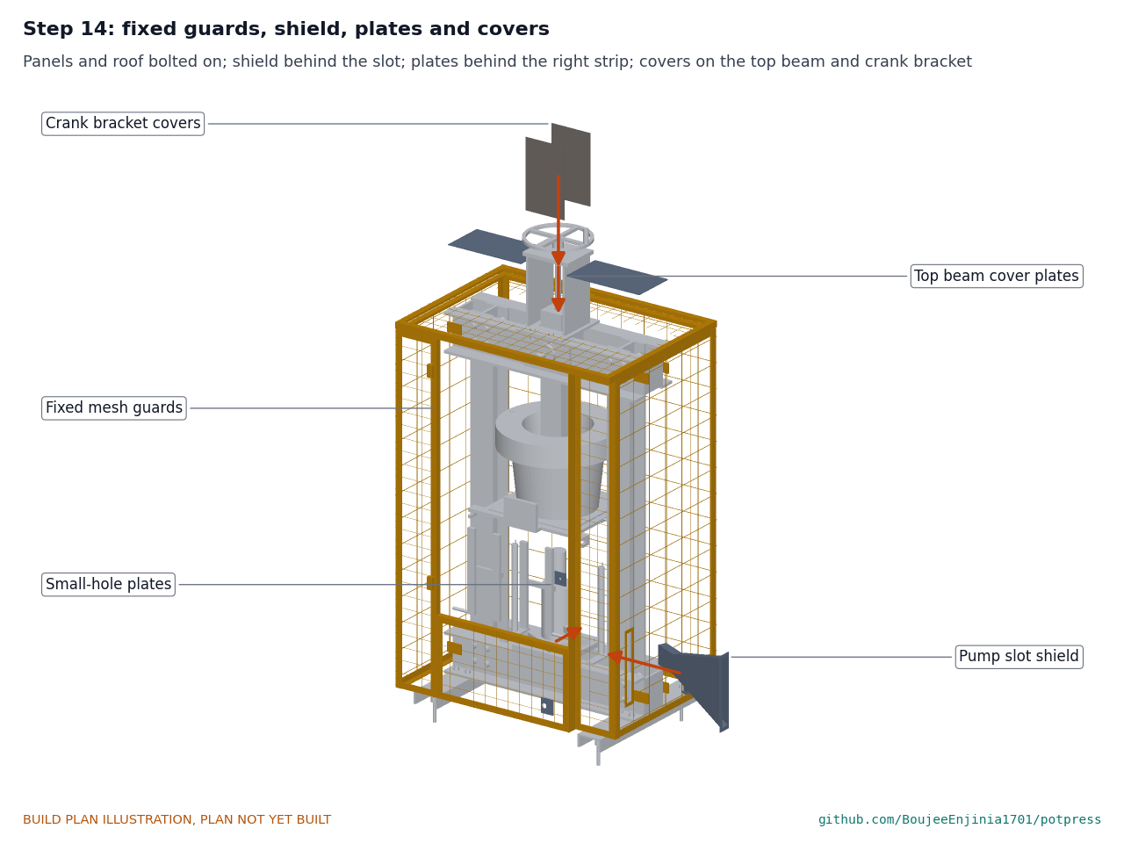
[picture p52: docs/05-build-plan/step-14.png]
Step 14


Bolt the standoffs to the beam webs. Fit the side, rear and front panels, the lower front panel and the roof, with M8 bolts at every corner. Slide the shield in from inside the guard along the handle's line until its flange meets the slot frame; bolt the flange through the frame and the stay to the base beam. Bolt the two cover plates onto the top beam and the two covers onto the crank bracket. Leave the small-hole plates loose behind the right front strip until step 16 threads the shaft and cable through them.

### Step 15: front gate

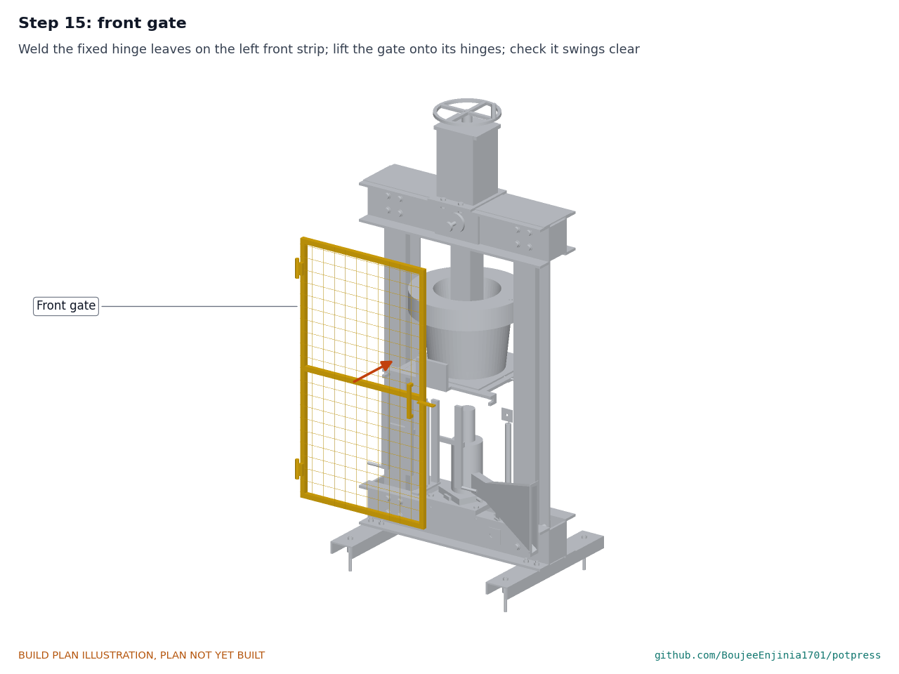
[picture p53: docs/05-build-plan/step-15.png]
Step 15


Weld the fixed hinge leaves to the left front strip's frame, lift the gate onto its hinges and check it swings clear of the folded extension.

### Step 16: interlock and pump handle

Step 16

Fit the coupling on the release screw, the shaft with its universal joints, the disc and the knob; the post, lock rod and sliders; the plunger over the pin head and its cable to the pin slider. Thread the shaft and the cable through the small-hole plates and bolt the plates on behind the right front strip. Put the pump handle in through the slot and along the shield into the socket. **Hold point:** safety stop S7.

### Step 17: QC rack

Step 17

Stand the welded frame on a level, drained floor and drop in the two shelves.

### Step 18: buckets, pots and gauge

Step 18

A bucket on the lower shelf under each hole; the pots hang by their rims; the gauge rests across a rim.

## 5. First checks

These are the checks a TRL 4 test report would record; this plan only lists them. Requirement numbers are those of PPR-REQ-001. None involves pressing clay or more than hand pressure.

*Table 2. First checks.*

| Check | Requirement | How | Pass when |
| --- | --- | --- | --- |
| Mold shape | R1 | Printed templates and callipers on both molds | Within 0.3 mm of the template radii |
| Mold closure and wall | R2 | Close the molds on the stop by hand with soft modelling-clay pads at eight places in the wall gap; open and measure the pads | Wall 15 mm, give or take 1; the molds line up within 0.5 mm |
| Stop contact | R3 | Marking blue on the female stop ring; close by hand | Even contact all round the ring |
| Opening | R5 | Jack down, crank up; measure the male tip above the female rim | At least 30 mm (70 mm designed) |
| Stroke used | R5 | Measure ram travel from first mold contact to closed | Within the jack's 150 mm stroke (110 mm designed) |
| Heaviest part | R8 | Weigh each part as lifted | 40 kg or less (platen 39.6 kg designed) |
| Gate interlock | R9 | Release open, no pressure: try to close the release with the gate open; close it with the gate shut, then try to open the gate | Neither is possible |
| Pin interlock | R9 | Gate shut, pin drawn back 10 mm: try to close the release | Not possible |
| Pump handle | R9 | Pump the handle over its full stroke by hand, release open | Never touches the slot frame or the shield; at each end of the stroke it stops at least 25 mm short of the slot ends |
| Guard openings | R9 | A competent person reviews the ISO 13857 desk check (all 23 openings meet on paper, PPR-CAL-001 v0.10) against the guards as built and signs it; push on the 6.35 mm mesh by hand to see it keeps its shape | Every opening meets the standard |
| Footprint | R11 | Measure the guarded press, extension folded, and the rack | Within 1.0 x 0.7 x 2.0 m and 0.8 x 0.8 m |
| Gauge scale | R6 | Draw off 1.0 L and 2.5 L measured volumes | 16.7 mm and 42.6 mm within 1 mm |
| Mold materials | R12 | Foundry scrap note; look at the mold faces | Lead-free; no paint or oil on the faces |
| Parts cost | R10 | Sum the receipts | Recorded against the value-engineering target |

## 6. Safety stops

Stop at each point. Carry on only when everything listed is true.

- **S1. Before any work.** Welding area ventilated, fire extinguisher at hand, welding helmet, leather gloves and apron, safety glasses and hearing protection in use; safety boots for all lifting.
- **S2. Before the foundry pour (done by the foundry).** The pattern is sealed and dry; the scrap is declared lead-free. Nobody from the build team stands near molten metal.
- **S3. Before welding or grinding galvanised mesh.** The zinc is ground off where you weld, extraction is running, and a P2 or N95 respirator is worn; or clamp the mesh instead of welding it.
- **S4. Before any lift over 25 kg** (platen 39.6 kg, top beam 38 kg, female mold 36.5 kg, base beam 34 kg, uprights 29 kg, male mold 23 kg). Two people or the hoist; clear floor; nobody under a load.
- **S5. Before letting go of the top beam.** Both top joints have all four bolts in; the frame is anchored to the floor.
- **S6. Before the first pump of the jack, even without clay.** All 16 joint bolts tightened; the load pin fully home with its R-clip; nobody's hands between the molds or on the stem; pump slowly and stop at the first contact. The guards are not yet on, so this is the only time the jack moves without them, and only by hand to contact.
- **S7. Before the jack is used again after step 16.** Every guard panel, the pump slot shield and the gate fitted; the gate and pin interlock checks of section 5 passed with the release open; the pump handle clears the slot and the shield; nobody inside the guard.
- **S8. Before any force above hand pressure.** TRL 4 authorisation by Amish, a competent person present, an exclusion zone round the press, and the ISO 13857 desk check signed by a competent person with every guard opening meeting it. Never defeat an interlock or remove a guard.
- **S9. Clay work at the press.** Mix and trim wet; wear a P2 or N95 respirator for any dry clay work (silica).

## 7. Tools, skills and workspace

**Tools.** Metal bandsaw or 355 mm abrasive chop saw for channel up to UPN 160; 125 mm angle grinder with cut-off and flap discs; pillar drill to 22 mm with drills 6 to 22 mm; hired magnetic drill with 18 and 62 mm annular cutters; 16 mm reamer; M6, M8 and M12 taps; stick welder of about 160 to 200 A for 3.2 mm E6013; welding table, clamps and magnetic squares; torque wrench covering the M16 10.9 bolt torque (about 300 N·m, check the bolt maker's table); ring spanners 18, 19 and 24 mm; hoist or engine crane rated at least 250 kg (hire); two stepladders or a work platform; 3 m tape, 1 m steel rule, callipers to 300 mm, engineer's square, 600 mm spirit level, feeler gauges, marking blue; 3D printer with at least a 250 x 250 mm bed; die grinder with carbide burrs, files, abrasive paper to 240 grit, a sheet of 6 mm float glass at least 500 mm square; jigsaw or router with a trammel for the 316 mm shelf holes.

**Skills.** A competent stick welder for the load-path welds (doublers, jack pad, sleeves, pin block, stem to disc); ordinary shop skill for the rest. Care with a magnetic drill. Basic 3D printing and pattern finishing. A local aluminium foundry for the two castings, able to declare lead-free charge material. A machine shop only if you would rather have the pin turned and the stem bored than do it yourself. No electrical work: the press has no power.

**Workspace.** Keep the strip next to the right guard where the pump handle works clear: it stands out about 160 mm beyond the guard, and the general arrangement outlines it on the floor. A covered, level concrete floor about 5 x 4 m with 3 m clear height for standing the uprights and lowering the top beam; a separate ventilated welding and grinding area; a clean bench for patterns and mold finishing; a level, drained spot for the QC rack.

**Personal protective equipment.** Welding helmet, leather gloves and apron; safety glasses for cutting, drilling and grinding; hearing protection; safety boots with toe caps for every lift; a fitted P2 or N95 respirator for galvanised mesh, PLA and filler sanding and dry clay; nitrile gloves for epoxy.

## 8. Where the numbers come from

- Model and constructability checks: `cad/src/model.py` (`python cad/src/model.py --check`, closed, open and demolding positions); STEP and STL exports in `cad/step/` and `cad/stl/`.
- Pictures: `cad/src/build_plan_media.py`, using `.kit/build_views.py`; written to `docs/05-build-plan/` and `cad/drawings/PPR-DWG-101` to `PPR-DWG-114`.
- General arrangement: `cad/drawings/PPR-DWG-001.pdf`, Rev P6, with the pump handle's operating space on the floor.
- Calculations: `docs/04-calcs/01-sizing.md` (PPR-CAL-001 v0.10) and `docs/04-calcs/sizing.py`; frame and joints section 4, travel and crank section 5, alignment section 7, patterns section 8, masses section 10, tipping section 11, ISO 13857 desk check section 15.
- Bill of materials: `bom/bom.csv`.
- Decisions: `docs/decisions/0004-design-for-construction.md` (PPR-DDR-004), with PPR-DDR-001 to PPR-DDR-003.
- Requirements: `docs/03-requirements.md` (PPR-REQ-001 v0.11).
- Design decisions register: `docs/06-design-decisions.md` (PPR-DEC-001 v0.4).

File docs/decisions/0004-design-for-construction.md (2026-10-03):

---
doc_id: PPR-DDR-004
title: PotPress design for construction
project: PotPress
doc_type: Design decision record
version: "0.5"
status: Draft
date: '2026-10-02'
author: Amish Chadha
license: CERN-OHL-S-2.0
revisions:
- version: "0.1"
  date: '2026-09-30'
  author: Amish Chadha
  change: Changes that make the concept physically buildable, with the reason for each, made under Amish's 2026-09-30 instruction
- version: "0.2"
  date: '2026-09-30'
  author: Amish Chadha
  change: Accepted by Amish; items that would change what the press does, its pitch, its safety case or its budget stay proposed (Table 3)
- version: "0.3"
  date: '2026-10-01'
  author: Amish Chadha
  change: Budget treated as a value-engineering target
- version: "0.4"
  date: '2026-10-02'
  author: Amish Chadha
  change: 'Q2, Q3 and Q5 decided by Amish on 2026-10-02 as recommended (Q2 amended: 30 mm slot only with a fixed inner shield, ISO 13857 check now); record stays Draft'
- version: "0.5"
  date: '2026-10-02'
  author: Amish Chadha
  change: 'Decisions carried into the design: pump slot shield modelled, slot lengthened to 272 mm, handle operating space on the GA floor layout; record stays Draft'
---

# 0004: Design for construction

- **Date:** 2026-09-30
- **Status:** accepted. Amish, 2026-09-30: "i accept your recommended changes on design that are currently being sent across for my approval". This covers every change in Tables 1 and 2. The questions in Table 3 would change the pitch or the safety case, or note value engineering, so they stay **proposed, awaiting Amish**. On 2026-10-02 Amish approved the recommendations for Q2, Q3 and Q5 ("i approve your recommendations for all 555 open decisions."); they are decided as recorded in Table 3 and in the design decisions register (PPR-DEC-001). Q1 is a value-engineering note, not a decision, and Q4 (the interlock notch) is set to the jack bought, under "To confirm when parts are bought" in the register.

## Context

On 2026-09-30 Amish rejected a text-only build plan and asked for one that shows, stage by stage and in pictures, how each component is made and how it fits the next, adding: "If you are realising that the design cannot be built as per concept - fix the design assumptions to match and be physically feasible as you draw the illustrations." An earlier planning pass that day found ten problems (P1 to P10) in the TRL 3 concept model of PPR-DDR-003. Checking the model with build123d in its closed, open and demolding positions found seven more (P11 to P17).

The changes keep what the press does: the same filter shape, 20 t jack, 600 mm frame, pressing travel, crank lift, guards, gate and QC rack, and the same pitch. The safety case is unchanged except where Table 3 says so. Every change is in `cad/src/model.py`, which now runs its constructability checks with `python cad/src/model.py --check`: no two of the 51 components overlap with the press closed, open or set for demolding; the 47 joints that must touch do touch; the pump handle clears the guard over its whole stroke; the carriage hooks meet the tipping pins; and the lock rod drops into the lock disc's notch. All pass.

## Decision

*Table 1. Changes made to the model, the BOM and the calculations.*

| # | Problem in the concept | Change made | Why this way |
| --- | --- | --- | --- |
| P1 | The male mold was a closed hollow: a sand core inside it could not be supported or removed. | The plug is open at the top. Its inside is a cone, 206 mm across at the floor and 259 mm at the flange, with the wall's own 6° draft. The pattern is flat-backed, flange face down, so the sand forms the inside as a green-sand core; no core box. | The simplest casting a jobbing foundry makes. The 15 mm shell and 30 mm tip are unchanged. |
| P2 | The 25 mm male flange, loaded on the stop ring and backed only by a 180 mm adapter, would reach about 487 MPa at 294 kN (as-cast yield about 90 MPa). | The flange is 45 mm thick and 450 mm across. The stem's 190 mm disc bears on the plug floor inside, bedded on steel epoxy putty and held by four M12 bolts, so the flange is a ring cantilevered from the plug wall: 62 MPa at 294 kN with all the force on the stop. | Thickening the flange is simpler than ribs and keeps the pattern flat-backed. The male mold is 23 kg, inside R8. |
| P3 | The molds located on a 390 mm lip fitted to 0.1 mm, which needs a 420 mm lathe; the patterns had no machining allowance, draft or core prints. | Two 16 mm hardened dowels pressed into the female flange at 202 mm each side, and two steel bushes in the male flange, drilled with the molds clamped together on printed 15 mm wall spacers. The stop faces are lapped flat on abrasive paper on float glass. Patterns carry 1.3 % shrink, 3 mm lapping allowance on the stop faces and the female base, and 2° draft on the flange rims. The female mold is a cast cup bedded and screwed on a 350 x 350 x 15 mm steel base plate. | Every operation fits a pillar drill and a bench. The dowels hold the wall even to about ±0.44 mm, as the lip did. The steel plate takes the rail contact and the retaining pins. |
| P4 | The jack's pump socket overlapped the right return spring, and the handle's path to the guard slot ran through the right upright. | The jack is turned 25° so its pump socket and release valve face the right front. The pump slot in the right side guard moves to 218 mm in front of the axis, on the handle's line, and widens from 25 to 30 mm so the 20 mm handle passes the 6 mm guard at 25° with about 2 mm clear. | The handle now misses the spring by 57 mm and the upright by 49 mm over its whole stroke. The 30 mm slot stays in the same ISO 13857 slot band (over 20 up to 30 mm); see Table 3, Q2. |
| P5 | The lead screw would have carried press force through the pin's 2 mm play. | The Tr24 nut is captive in a box at the top of the stem with 8 mm of free travel below it. Cranking up, the nut lifts the cap plate; pressing, the stem rides up about 2 mm onto the pin and the nut stays free. | No extra parts or bearings; the press force goes through the pin, never the screw. |
| P6 | The 100 mm uprights filled the 100 mm beam gap with no clearance. | The beam gap is 104 mm, with a 2 mm shim pack each side of each joint. | Rolled channel varies by a millimetre or two; shims take it up. |
| P7 | M20 bolts were too big for the 50 mm UPN 100 flange and clamped across an 83 mm hollow. | Four M16 grade 10.9 bolts per joint, 28 mm from the web (22 mm edge distance against 21.6 mm needed), with a 25 x 3 mm spacer tube inside the channel between the flanges. Double shear 117 MPa at 294 kN. | M16 is the largest bolt the flange takes; 10.9 gives the strength back. The tube stops the flanges folding when the bolts are tightened. |
| P8 | The carriage had tilt bosses but nothing to pivot on and nothing holding the mold in. | Two 12 mm bright steel tipping pins on the ends of the rail extension; two hooks on the carriage with slots open to the front that slide onto them; two 10 mm retaining pins through the carriage into the base plate; two lift handles near the back of the carriage. | The mold tips forward about the pins; about 283 N on the two handles starts the tip. The hooks cannot slide off under the mold's own weight. |
| P9 | The interlock was outline shapes only. | A concrete mechanism round a standard bottle jack release screw: a coupling on the screw, a 12 mm shaft with two universal joints out to a front knob, an 80 mm lock disc with one notch, a 12 mm lock rod on a guide post, a gate slider pushed back by the gate's tongue, and a pin slider pulled aside by a push-pull cable from a plunger on the load pin's head. With the valve open the rod drops into the notch; the valve can be closed only by lifting the rod, which needs the gate shut and the pin home; with the valve closed the rod stands through the gate tongue. | Purely mechanical, no electrics, as PPR-DDR-003 decided. The notch angle must be set to the jack bought (Table 3, Q4). |
| P10 | The feet had no flat face to bolt through; floor anchors, spring anchors, spacer tubes and shims were missing from the BOM; the QC buckets overlapped the hanging pots. | Feet turned web up with welded anchor tubes and four welded M12 studs each; four M12 floor anchors; spring lugs on the base beam and under the platen; tubes and shims modelled and in the BOM. The QC pot shelf is raised to 720 mm, leaving 35 mm between the pots and 325 mm buckets on the 120 mm shelf. | All in the model and `bom/bom.csv`. |
| P11 | Found in checking: the folded rail extension would hit the gate's bottom rail and the lower front panel's frame when the platen goes down. | The rail hinge line moves back from 320 to 290 mm in front of the axis; the extension is 335 mm long so the tipping pins stay where they were. | The folded extension now clears both with the platen down. The stop lug load rises to about 2.9 kN (10.8 kN with the mold tipped over). |
| P12 | Found in checking: when the crank lifts the stem, the pin block inside it would hit the fixed lower end of the lead screw after about 56 mm. | A 28 mm hole down the middle of the pin block and the nut box floor. | The screw passes freely over the full 200 mm lift. Pin bearing on the block rises from 54 to 79 MPa at 294 kN. |
| P13 | Found in checking: the stem had 7 mm of play front to back in the beam gap, more than the dowels' 3 mm lead-in. | Two 6 mm plastic strips on the inside faces of the top beam webs, with 62 mm holes for the pin, give 1 mm each side. | The dowels now always find their bushes. |
| P14 | Found in checking: the jack's pump handle was not part of the design. | A 20 mm handle, at least 700 mm long, bought with the jack or extended with tube, modelled over its stroke. | It stands 158 mm outside the right guard while in use (Table 3, Q3). |
| P15 | Found in checking: the stem could not be fitted with the molds in place, and the female mold could not slide in under a stem pinned at pressing height. | Assembly order set by the model: stand the stem on the rails before the top beam goes on; pin it; crank it up; put both molds together on the carriage out on the swung-out extension; slide them in; crank down; pin; jack up and bolt the male mold to the stem. | Shown step by step in PPR-BLD-001. |
| P16 | Found in checking: the female mold's plate would have borne on plastic slide strips under the full press force. | The base plate slides on the greased steel rails; the rails with the platen deck are checked across the platen's centre gap (101 MPa at 294 kN). | Plastic would creep under 294 kN. |
| P17 | Found in checking: the only carriage handle was in front of the tipping pins, so it could not tip the mold. | The two lift handles of P8. | |

*Table 2. Knock-on changes.*

| Item | Change | Reason |
| --- | --- | --- |
| Masses | Press 298 to 344 kg; heaviest part the platen at 39.6 kg (R8, 40 kg); female mold with its base plate 36.5 kg; male mold 23.0 kg. | Added parts, thicker flanges, steel base plate. |
| Calculations | PPR-CAL-001 v0.6: new checks for the male flange, the M16 joints, the lead screw float, the rails, the tipped mold, the stop lugs and the tipping pins; deflection 0.66 mm at 10 t. R3 stays met on paper. | Follows the model. |
| Requirements | PPR-REQ-001 v0.8: R10 now over the value-engineering target by $83; figures for R2, R3, R7, R8, R9 and R11 updated. No requirement text changed. | Follows the calculations. |
| BOM | Lines 1, 2, 3, 4, 7, 8, 9, 10, 12, 15, 16, 18, 20 and 21 rewritten to the buildable parts; total $1,051 to $1,143. | Parts added for construction. |
| Drawing | PPR-DWG-001 Rev P5; making sketches PPR-DWG-101 to 114 added. | Follows the model. |
| Media | Concept images, blueprint and 3D viewer regenerated. The photoreal renders (`media/render-*.png`) and `cad/src/product_model.py` still show the concept and need updating in Blender on Amish's Mac. | |

*Table 3. Questions that would change the pitch or the safety case; Q2, Q3 and Q5 decided by Amish on 2026-10-02.*

| # | Question | Options | Recommendation |
| --- | --- | --- | --- |
| Q1 | Value engineering (a note, not a decision). The constructable BOM is $1,143, $83 (7.8 %) over the $1,060 value-engineering target (`budget_usd`, a hypothetical control target). | (a) look for savings (for example cheaper dowels and bushes, plywood QC shelves from offcuts); (b) read the target against the press alone ($1,060). | (a); the added parts are what a build needs, so savings come from how they are bought. |
| Q2 | The pump slot widens from 25 to 30 mm. Both are in the same ISO 13857 band, but the guard distance check itself is still open (PPR-DDR-003). | (a) accept 30 mm with a brush strip and do the ISO 13857 check at TRL 4; (b) keep 25 mm and fit a thinner (16 mm) handle. | (a), as amended. **Decided by Amish, 2026-10-02:** keep the 30 mm slot, approved only with a fixed inner shield or tunnel behind the slot that keeps the platen and molds out of arm's reach, sized in the ISO 13857 desk check, which is done now rather than at TRL 4 (PPR-DDR-003). A brush strip does not count as a guard. |
| Q3 | The pump handle stands 158 mm outside the right guard while in use, beyond the 1.0 m width of R11. | (a) treat the handle as operating space, like a door swing, and keep R11 on the guarded box; (b) use a two-piece handle removed between cycles. | (a). **Decided by Amish, 2026-10-02:** the handle's 158 mm is operating space, marked on the floor layout; R11 applies to the guarded box. |
| Q4 | The interlock notch is 120° (a third of a turn) round from the rod. Bottle jacks open their release between about a quarter and a half turn. | (a) set the notch to the jack bought, at TRL 4; (b) fix it at 120° and buy a jack to suit. | (a). |
| Q5 | The mold is tipped over by hand on pins at the end of the extension to demold (about 51 kg in all). The method was always to be confirmed with potters (PPR-PRC-001). | (a) keep the tipping pins; (b) lift the pot out in its liner instead. | (a) for the prototype; confirm with a partner factory. **Decided by Amish, 2026-10-02:** keep the tipping pins; the potters at the first partner factory confirm the method, and if they object the pot is lifted out in its liner. |

## Carried into the design, 2026-10-02

- **Q2.** The fixed inner shield is in the model (`pump_shield`, BOM item 16): a tunnel of 2 mm folded sheet, 30 mm wide inside, along the handle's line from the slot to 3 mm off the jack body, with a flange bolted through the slot frame and a flat-bar stay to the base beam. The slot is lengthened from 220 to 272 mm (174 to 446 mm up) so that the handle stops 25 mm short of its ends and of the tunnel's roof and floor at both ends of its stroke. The constructability checks pass with the shield in all positions. Sized in the ISO 13857 desk check, PPR-CAL-001 section 15, which also found other openings short of the standard (now open decisions in PPR-DEC-001).
- **Q3.** The handle's operating space outside the right guard (158 mm) is outlined on the floor in the general arrangement PPR-DWG-001, Rev P6.
- **Q5.** No change to the design; confirmed with the partner factory's potters when one is chosen.

## Consequences

- `design_state: constructable` in `project.yaml`. The build plan PPR-BLD-001 (`docs/05-build-plan.md`) shows every component and step in pictures drawn from the model by `cad/src/build_plan_media.py`.
- Requirement status: 1 over the value-engineering target (R10), 2 at risk (R2, R7), 9 met on paper (PPR-CAL-001 v0.6).
- The photoreal renders and the appearance model are stale until they are rebuilt in Blender.
- TRL 4 remains on hold by Amish's instruction.

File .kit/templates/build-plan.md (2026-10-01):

---
doc_id: PRJ-BLD-001
title: Project prototype build plan
project: Project name
doc_type: Build plan
version: "0.1"
status: Draft
date: YYYY-MM-DD
author: Amish Chadha
license: CERN-OHL-S-2.0
revisions:
  - version: "0.1"
    date: YYYY-MM-DD
    author: Amish Chadha
    change: First build plan; design made constructable
---

# Project prototype build plan

**Plan, not yet built.** How to build the first proof-of-concept prototype, component by component. Building and testing to it is TRL 4 work. Decisions still to be made are kept in the design decisions register (`docs/06-design-decisions.md`), not here.

## 1. What you are building

Every component, pulled apart and numbered in build order

One short paragraph: what the prototype is, how many components, which are made and which are bought, and the main ways they are made.

## 2. What changed to make it buildable

| Component | The concept had | The buildable design has | Why |
| --- | --- | --- | --- |

## 3. Making the components

### 3.1 Component name

Making sketch

**What it is and what it is made from.**

**How to make it.**

1. Mark out ...
2. Cut ...

**How it fits the parts next to it.**

Close-up of the joint

**Check before moving on.**

## 4. Putting it together

### Step 1: ...

Step 1

## 5. First checks

| Check | Requirement | How | Pass when |
| --- | --- | --- | --- |

## 6. Safety stops

## 7. Tools, skills and workspace

## 8. Where the numbers come from

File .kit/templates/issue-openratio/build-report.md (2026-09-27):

---
name: Build report
about: Tell us what happened when you built, printed or tested part of this design
title: "Build report: "
labels: build-report
---

This is a research and educational prototype, not a medical device. It is a TRL 3 concept and is not released for fabrication. If you build any part of it, you do so at your own risk. Reports help everyone.

**What you built** (part, sub-assembly or test)

**Materials, tools and settings**

**What worked**

**What did not work, with photos or measurements if you have them**

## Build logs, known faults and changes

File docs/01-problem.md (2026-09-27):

---
doc_id: PPR-PRB-001
title: PotPress problem statement
project: PotPress
doc_type: Problem statement
version: "0.6"
status: Draft
date: '2026-09-27'
author: Amish Chadha
license: CERN-OHL-S-2.0
revisions:
- version: "0.1"
  date: '2026-09-24'
  author: Amish Chadha
  change: Initial scaffold
- version: "0.2"
  date: '2026-09-25'
  author: Amish Chadha
  change: Populate to TRL 2 (users, context, constraints, out of scope, prior work with sources, co-design checklist)
- version: "0.3"
  date: '2026-09-25'
  author: Amish Chadha
  change: Budget constraint $720 as decided by Amish (PPR-DDR-001); Penn State press paper checked; partner question left open
- version: "0.4"
  date: '2026-09-25'
  author: Amish Chadha
  change: Recommendations accepted by Amish (DDR-002); budget constraint $930; lead-free scrap in the constraints
- version: "0.5"
  date: '2026-09-26'
  author: Amish Chadha
  change: Budget top-up approved by Amish; budget constraint $990
- version: "0.6"
  date: '2026-09-27'
  author: Amish Chadha
  change: Budget raised by Amish on 2026-09-27; budget constraint $1,060
---

# PotPress problem statement

Ceramic pot filters work well, but local producers have no low-cost way to form them consistently. The presses in use are either imported at about $3,000 to $3,500 or built one at a time from drawings that are not openly maintained, and filter quality depends on how evenly each pot is pressed and on a manual flow-rate check. PotPress is an open, garage-buildable filter press with parametric mold geometry, paired with a simple flow-rate test rack, so that a small factory can make and check filters consistently for well under the cost of an imported press. Design with, not for: requirements must come from co-design sessions and field trials with the intended users through a local partner.

## The problem

About 2.1 billion people still lacked safely managed drinking water in 2024, and 106 million drank untreated surface water ([WHO and UNICEF JMP, 2025](https://www.who.int/news/item/26-08-2025-1-in-4-people-globally-still-lack-access-to-safe-drinking-water---who--unicef)). Household water treatment fills the gap where piped, treated water will not arrive soon.

The ceramic pot filter is one of the best-studied household options. It is a flowerpot-shaped vessel of fired clay mixed with a burnout material such as sawdust or rice husk, usually coated with colloidal silver or silver nitrate, that sits in a plastic or ceramic receptacle with a tap. The design dates from 1981, when Dr. Fernando Mazariegos developed it at ICAITI in Guatemala; Potters for Peace spread it after Hurricane Mitch in 1998, and it is now made by more than 50 independent workshops in over 30 countries, typically about 280 mm wide by 250 mm deep (11 by 10 in) with a flow of 1.5 to 2.5 L/h ([Potters for Peace](https://www.pottersforpeace.org/ceramic-water-filter-project)). In a randomized trial in Cambodia, households using locally made filters had about half as much diarrheal disease as controls (longitudinal prevalence ratio 0.51) ([Brown, Sobsey and Loomis, 2008](https://researchonline.lshtm.ac.uk/id/eprint/1699/)), and laboratory tests of the same filters showed a mean E. coli reduction of about 99 % ([Brown and Sobsey, 2010](https://iwaponline.com/jwh/article/8/1/1/1877/Microbiological-effectiveness-of-locally-produced)).

The technology is proven, but making it well is hard for a small workshop:

1. **The press is the costly item.** The Potters for Peace press uses a 20 t hydraulic jack, a removable female mold and a male mold on a movable shaft, and costs about $3,000 to $3,500 imported before shipping and duties. A press built locally in Nigeria from cast iron, steel and scrap aluminum cost about $1,000 ([Manufacturing a Ceramic Water Filter Press for Use in Nigeria, IntechOpen](https://www.intechopen.com/chapters/71402)), and a Penn State team designed a press to cost under $200 and be built by two people in two days, against $2,300 for the Potters Without Borders press (over $3,000 with labor), forming round-bottom filters with a 2 t car jack ([Henry, Maley and Mehta](https://sites.psu.edu/hese/2016/03/16/designing-a-low-cost-ceramic-water-filter-press/); [paper, IJSLE 8 (1), 2013](https://ojs.library.queensu.ca/index.php/ijsle/article/view/4532)). Neither is maintained as an open, parametric design.
2. **Mold making needs tools the workshop may not have.** The Nigerian team had trouble finding a lathe large enough to finish the cast molds, and dimensioning errors in the drawings had to be corrected during machining (IntechOpen chapter above).
3. **Consistency decides whether a filter works.** Flow rate and bacteria removal depend on the burnout ratio, burnout particle size and firing temperature; for example, larger rice husk particles raised flow but cut E. coli log reduction from 2.8 to 0.7 ([Heijman et al., 2015](https://www.academia.edu/68960939/Critical_parameters_in_the_production_of_ceramic_pot_filters_for_household_water_treatment_in_developing_countries)). An even wall, pressed to the same thickness every time, is the part of that chain the press controls.
4. **Quality control is manual and varies by factory.** Factories soak each fired filter for 4 to 24 h, fill it and measure the drop after one hour with a calibrated dipstick (a "T-device"), but acceptance bands differ: 2.0 to 3.0 L/h at one factory, 1.5 to 3.0 L/h at another and 1.0 to 2.5 L/h in the first hour in Nicaragua ([Rayner, 2009, WEDC](https://bdd.pseau.org/outils/ouvrages/wedc_current_practices_in_manufacturing_locally_made_ceramic_pot_filters_2009.pdf)). Industry guidance is gathered in the Ceramics Manufacturing Working Group's best practice recommendations ([CMWG, 2011](https://www.ircwash.org/sites/default/files/CMWG-2011-Best.pdf)).

## Users and context

| User | Need | Context |
| --- | --- | --- |
| Small filter factory or pottery cooperative | Press 50 or more filters a day with even walls; replace or repair the press locally | Three to four workers, a kiln, a mixing area and drying racks |
| NGO or social enterprise starting a factory | A press and QC rig it can build or commission locally instead of importing | Start-up budget, often in a region without a filter factory yet |
| Local fabrication shop | Build the frame and have the molds cast from open drawings | Stick welder, drill press, hand tools; access to an aluminum foundry is uncertain |
| QC technician | Test every fired filter for flow and record the result the same way each time | Soaking tanks, buckets, a timer; results logged by hand |
| University or research lab | A repeatable press to study mix, pressing and firing variables | Lab bench or workshop; needs repeatability more than throughput |

### Operating environment

- **Material:** a damp, stiff mix of about 60 to 70 % clay by mass with rice husk or sawdust and water; about 8 to 9.5 kg of mix per filter ([Rayner, 2009](https://bdd.pseau.org/outils/ouvrages/wedc_current_practices_in_manufacturing_locally_made_ceramic_pot_filters_2009.pdf)). Clay and burnout dust is abrasive and wet.
- **Workshop:** open-sided shed, 15 to 40 °C, high humidity in the wet season, earth or concrete floor, intermittent or no mains power.
- **Duty:** one pressing about every 5 min over a shift, 6 days a week (estimate).
- **Supply chain:** steel channel, plate, bottle jacks and hardware are available in most regional towns; aluminum casting may mean a trip to a city foundry; 3D printing is available at universities and maker spaces.

## Constraints

- Garage-buildable prototype, $1,060 USD in parts (raised from $600 to $720 and then to $930 by Amish on 2026-09-25, PPR-DDR-001 and PPR-DDR-002; topped up to $990 by Amish on 2026-09-26; raised to $1,060 by Amish on 2026-09-27 for the guarded version, PPR-DDR-003).
- Frame buildable with a stick welder, grinder and drill press; no machining that needs a large lathe or mill.
- No mains power needed to press or to run the flow test; hand-pumped hydraulics only.
- Mold geometry defined parametrically so that a factory can change size or wall thickness and generate new patterns and gauges from the same source.
- Everything that touches the clay or the test water must not contaminate a drinking-water product; molds are cast from lead-free scrap (decided by Amish, 2026-09-25).

## Out of scope

- The filter formulation, kiln, firing schedule and silver treatment. PotPress presses and checks the pot; it does not change the recipe. Silver application is noted only for safety.
- The receptacle, lid and tap of the household unit.
- Certification of the filters. Factories should follow the CMWG recommendations and the WHO scheme for evaluating household water treatment products ([WHO](https://www.who.int/tools/international-scheme-to-evaluate-household-water-treatment-technologies)).
- Powered or automated presses.

## Prior work

- **Potters for Peace press and factory model.** The reference design and factory practice that most filter workshops use; a 20 t jack press with a removable female mold ([IntechOpen chapter](https://www.intechopen.com/chapters/71402); [Potters for Peace](https://www.pottersforpeace.org/ceramic-water-filter-project)).
- **Locally built presses.** The Nigerian press at about one-third of the imported cost, and the Penn State low-cost press ([Henry, Maley and Mehta](https://sites.psu.edu/hese/2016/03/16/designing-a-low-cost-ceramic-water-filter-press/)).
- **Manufacturing practice surveys.** Rayner's survey of factory practice, including presses (screw and hydraulic), mold materials (aluminum, cast iron, wood and cement), mixes, firing and QC ([Rayner, 2009](https://bdd.pseau.org/outils/ouvrages/wedc_current_practices_in_manufacturing_locally_made_ceramic_pot_filters_2009.pdf)), and the CMWG best practice recommendations ([CMWG, 2011](https://www.ircwash.org/sites/default/files/CMWG-2011-Best.pdf)).
- **Performance studies.** Health and microbiological effect ([Brown, Sobsey and Loomis, 2008](https://researchonline.lshtm.ac.uk/id/eprint/1699/); [Brown and Sobsey, 2010](https://iwaponline.com/jwh/article/8/1/1/1877/Microbiological-effectiveness-of-locally-produced)) and production parameters ([Heijman et al., 2015](https://www.academia.edu/68960939/Critical_parameters_in_the_production_of_ceramic_pot_filters_for_household_water_treatment_in_developing_countries)).

## Open questions

- Which partner factory or organization first (for example an existing Potters for Peace network factory, an NGO planning a new factory, or a university ceramics lab)? Proposed, awaiting Amish; under the portfolio rule, partners are picked per area later.
- Which reference filter size to model first: the common 280 by 250 mm form, or the partner's own mold?
- Is a local aluminum foundry within reach of the first partner, or must the molds use another material?
- What flow acceptance band does the partner use, and does it correct for water temperature?

## User research and co-design

This design is for communities the author is not part of, so requirements come from the people who will use it.

- [ ] Identify a local partner organization (Helpful Engineering network, NGO or university)
- [ ] Run co-design sessions with intended users; record who, where and what was learned
- [ ] Validate filter size, throughput, pressing and cost assumptions with a working filter factory
- [ ] Revise requirements (REQ) from findings before freezing the design

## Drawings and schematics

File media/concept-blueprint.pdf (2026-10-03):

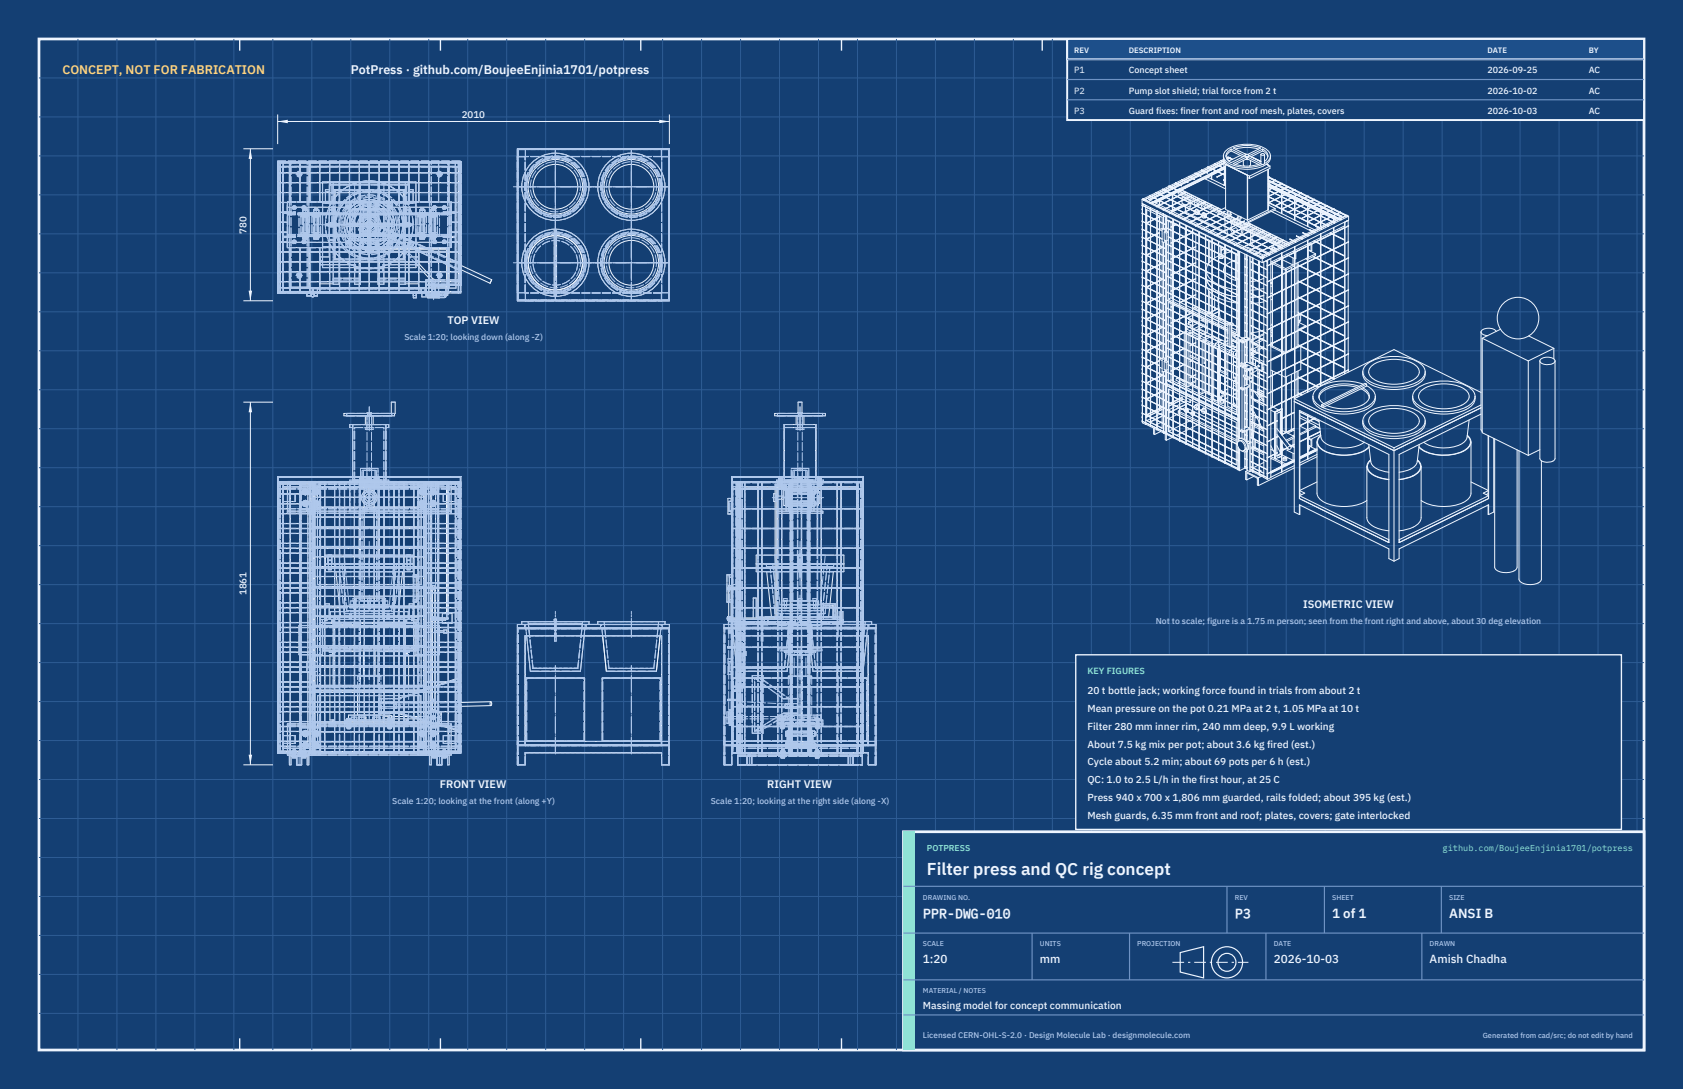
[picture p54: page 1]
CONCEPT, NOT FOR FABRICATION; PotPress · github.com/BoujeeEnjinia1701/potpress; FRONT VIEW; TOP VIEW; RIGHT VIEW; ISOMETRIC VIEW; REV; DESCRIPTION; DATE; Concept sheet; Pump slot shield; trial force from 2 t; Guard fixes: finer front and roof mesh, plates, covers; POTPRESS; github.com/BoujeeEnjinia1701/potpress; DRAWING NO. PPR-DWG-010; REV P3; SHEET 1 of 1; SIZE ANSI B; SCALE 1:20; UNITS mm; PROJECTION; DRAWN Amish Chadha; Licensed CERN-OHL-S-2.0 · Design Molecule Lab · designmolecule.com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

Scale 1:20; looking down (along -Z)

Not to scale; figure is a 1.75 m person; seen from the front right and above, about 30 deg elevation

KEY FIGURES
20 t bottle jack; working force found in trials from about 2 t
Mean pressure on the pot 0.21 MPa at 2 t, 1.05 MPa at 10 t
Filter 280 mm inner rim, 240 mm deep, 9.9 L working
About 7.5 kg mix per pot; about 3.6 kg fired (est.)
Cycle about 5.2 min; about 69 pots per 6 h (est.)
QC: 1.0 to 2.5 L/h in the first hour, at 25 C
Press 940 x 700 x 1,806 mm guarded, rails folded; about 395 kg (est.)
Mesh guards, 6.35 mm front and roof; plates, covers; gate interlocked

Scale 1:20; looking at the front (along +Y)

Scale 1:20; looking at the right side (along -X)

Filter press and QC rig concept

MATERIAL / NOTES
Massing model for concept communication

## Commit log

2026-09-24 Initial scaffold: standard open hardware layout, CERN-OHL-S v2 + MIT licenses
    Claude-Session: https://claude.ai/code/session_01XuhhSU4W6fYhgCfURbrkut
    [bom.csv]
2026-09-25 Adopt portfolio kit v1.3.0: session commands, scale figure, 3D viewer, flow diagrams
    Adds .claude/commands (/populate, /advance-trl3, /rein-in, /refresh-media)
    so every Claude Code session starts from the standard prompts, and extends
    concept media with a 1.75 m scale figure, an interactive glTF viewer and
    system or energy flow diagrams. TRL cap 3 unchanged.
    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
2026-09-25 Kit v1.3.1: renderer fixes from the TremorTrace pilot
    Context scale parts for small objects, cutaway exclusions, and text
    labels in flow diagrams.
    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
2026-09-25 Populate potpress to a strong TRL 2 with concept media (batch 6)
    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
    [bom.csv]
2026-09-25 Advance potpress to TRL 3 (batches 5 and 6)
    Decisions approved by Amish 2026-09-25 recorded in DDR-001. TRL 4 is on hold.
    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
    [bom.csv, female-mold.step, female-mold.stl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]
2026-09-26 Accept all recommendations (DDR-002), switch footer to designmolecule.com, add README write-up with new inspiration point
    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
    [bom.csv, female-mold.step, filter-pot.step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]
2026-09-27 Product appearance model and photoreal renders
    Adds cad/src/product_model.py (appearance model for renders only, all main
    dimensions from model.py) and Blender renders in media/render-*.png,
    captioned with the project, repository and viewing direction. README leads
    with the product render; trl stays 3.
    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
2026-09-27 Guarded version: fixed mesh guards and interlocked front gate
    Adds welded mesh guards on the sides, back and roof and a hinged front gate
    with a mechanical interlock on the jack release valve (PPR-DDR-003). BOM,
    concept and requirements (v0.6), sizing (PPR-CAL-001 v0.4), GA drawing
    (Rev P3) and concept media updated. Estimated cost 1,051 USD against the
    990 USD budget: the overrun is proposed, awaiting Amish. ISO 13857 distances
    are a stated assumption, not yet checked against the tables.
    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
    [bom.csv, female-mold.step, filter-pot.step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]
2026-09-27 Budget raised to 1,060 USD for the guarded version
    Amish approved the recommended budget on 2026-09-27 (PPR-DDR-003 v0.2).
    R10 is met: 1,051 USD against 1,060 USD. Concept, requirements, sizing,
    problem statement, BOM notes, README and GA drawing (Rev P4) updated.
    ISO 13857 distances remain a stated assumption, awaiting Amish.
    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
2026-10-01 Kit 1.7.0: constructable design, illustrated build plan and design decisions register
    The design is now constructable (decision record Design for construction, accepted by Amish on 2026-09-30). docs/05-build-plan.md shows how to make and fit every component, with making sketches, join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
    [bom.csv, female-mold.step, female-mold.stl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]
2026-10-01 Budget treated as a value-engineering target
    Amish, 2026-10-01: the budget is a hypothetical control target that keeps the design on a value-engineering lens, not a spending limit. Documents now state the value-engineering target and the estima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
2026-10-02 Record Amish's approval of the open-decision recommendations
    Amish approved the recommendation on every open decision in the design decisions register ("i approve your recommendations for all 555 open decisions.", 2026-10-02). Each decision is moved to Decisio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
2026-10-03 Carry approved follow-ups into the design and redo photoreal renders
    Amish approved the follow-up actions from the open-decision sign-off ("APPROVED CHANGES, COMPLETE THESE", 2026-10-02), the design-for-construction change tables in ten repos, the last wave's open dec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
    [bom.csv, female-mold.step, filter-pot.step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]
2026-10-03 Record Amish's 2026-10-03 decisions; FlatTrike fork and PotPress guard fixes
    Amish, 2026-10-03: "PalletPilot - i accept it"; "FlatTrike - i accept your design recommendation, proceed and execute the solution for fork direction or caster"; "PotPress - move forward with the four guard fixes. I accept the cost."; "GravitySort - i accept your recommendation"; "TIght Margins - i accept the margins"; "Cost over target - i accept all the cost variations and overruns". FlatTrike knuckle forks turned to trail (35 mm trail); PotPress finer mesh, small-hole plates, top beam and crank bracket covers, ISO 13857 desk check now met on paper. Registers, requirements, drawings, pictures, renders and PDFs upd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
    [bom.csv, female-mold.step, filter-pot.step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]
2026-10-28 Kit 1.9.1 upgrade: pipeline documents and detailed CAD for every option
    Kit 1.9.1 installed (.kit, CLAUDE.md, .claude/commands). Kit 1.8 pipeline: STEM check with fixes under the 2026-10-23 standing instruction, concept options with the current design as option A, URS, PRS, generated RTM, REG, FEA, RSK with design FMEA, MKT, PLN and DDR; kit 1.9 D3 model of every option passing cad/fidelity.json; independent review recorded in the STEM check. Amish's 2026-10-25 decisions recorded where he approved a recommendation; all others proposed, awaiting Amish. Product renders and the options picture follow in a later commit where not yet included.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
2026-10-29 Add Cycles product renders and the concept options picture
    Blender Cycles renders of the kit 1.9.1 model, rendered on Amish's Mac and captioned; media/options.png from the D3 option models (this also clears the failing docs check, which needs the picture); cards and PDFs rebuilt. The options picture labels option A as the current design unless project.yaml records Amish's choice.
2026-10-29 Add the concept options picture rendered from the D3 option models
    media/options.png from Blender Cycles panels of every option, rendered on Amish's Mac; the label reads CURRENT DESIGN unless project.yaml records Amish's choice. Clears the docs check, which needs th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

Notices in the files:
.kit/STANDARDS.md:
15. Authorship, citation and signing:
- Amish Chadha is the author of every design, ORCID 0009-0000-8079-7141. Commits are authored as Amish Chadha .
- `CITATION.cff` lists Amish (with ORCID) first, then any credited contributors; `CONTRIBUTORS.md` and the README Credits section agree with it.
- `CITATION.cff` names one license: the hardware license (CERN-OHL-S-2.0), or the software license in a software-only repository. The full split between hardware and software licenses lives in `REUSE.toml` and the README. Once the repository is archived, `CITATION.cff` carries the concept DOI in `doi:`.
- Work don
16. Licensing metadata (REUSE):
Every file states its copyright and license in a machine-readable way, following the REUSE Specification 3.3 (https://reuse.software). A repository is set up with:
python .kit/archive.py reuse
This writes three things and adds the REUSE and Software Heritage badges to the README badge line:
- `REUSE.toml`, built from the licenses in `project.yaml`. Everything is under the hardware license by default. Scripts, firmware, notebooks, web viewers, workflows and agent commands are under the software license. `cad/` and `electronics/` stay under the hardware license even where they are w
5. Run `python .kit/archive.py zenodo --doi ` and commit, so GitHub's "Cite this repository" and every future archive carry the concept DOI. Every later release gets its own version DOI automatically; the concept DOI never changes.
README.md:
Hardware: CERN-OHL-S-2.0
